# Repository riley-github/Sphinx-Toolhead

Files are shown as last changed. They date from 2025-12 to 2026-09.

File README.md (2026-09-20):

# Sphinx Toolhead

**File repository for the Sphinx toolhead**

Sphinx toolhead is aimed to be a high-performance toolhead with an emphasis on part cooling and rigidity.  
This project was built around the goal of printing a **quality 4-minute PLA Benchy**.  

Sphinx is a **work in progress!** If you have any suggested feel free to reach out of discord!

If you use this toolhead and modify or remix, please upload here or let me know on Instagram or Discord!  
📸 Instagram: [@practically_printed](https://instagram.com/practically_printed)  
💬 Sphinx Development Channel: [sphinx-dev](https://discord.gg/Rgn6Q9szn)

---

---

## 🧩 Notes

The current and most up to date version of Sphinx is called Sphinx tLW. This version utilizes a micro bowden approach in order to optimize for COM while not compromising on toolhead rigidity and so far has proved to work very well. 

- **Print Settings:** 8 walls, 8 top/bottom layers, 40% infill
- Print at least 4 of the Apex clips in either the Voron or Monolith folder

---

## 📸 Pictures (Sphinx tLW)

| | |
|:---:|:---:|
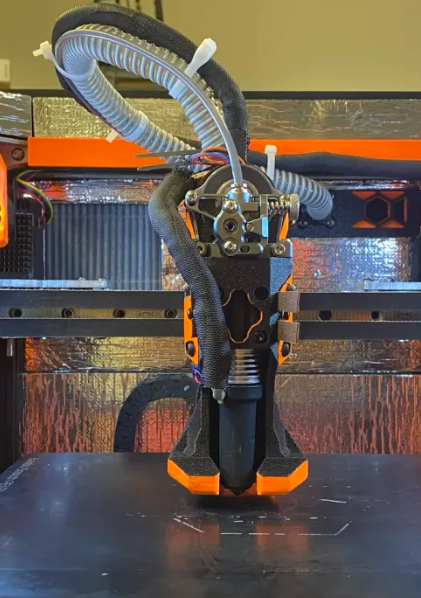
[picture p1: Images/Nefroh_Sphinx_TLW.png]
Nefroh Sphinx tLW
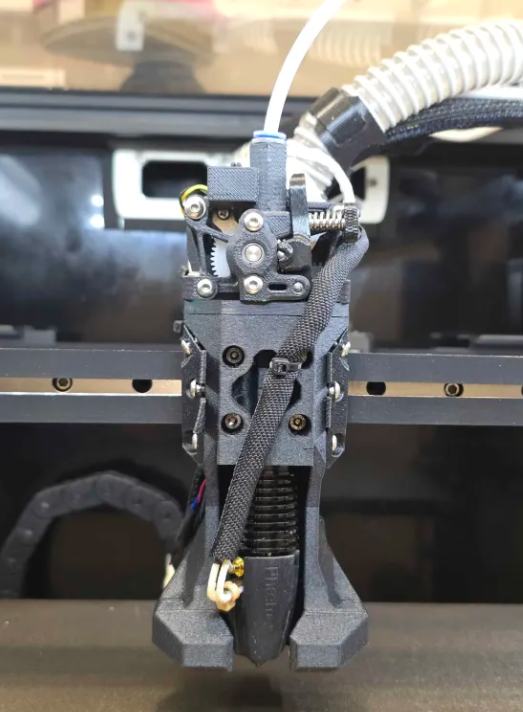
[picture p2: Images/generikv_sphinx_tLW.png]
generikv Sphinx tLW
|  |  |

Big thanks to discord users xyglotop and generikv for these images

---

## 📈 Input Shaper Results

| X IS Graph | Y IS Graph |
|:---:|:---:|
|  |  |

---

## ⚙️ Mass Specs / COM

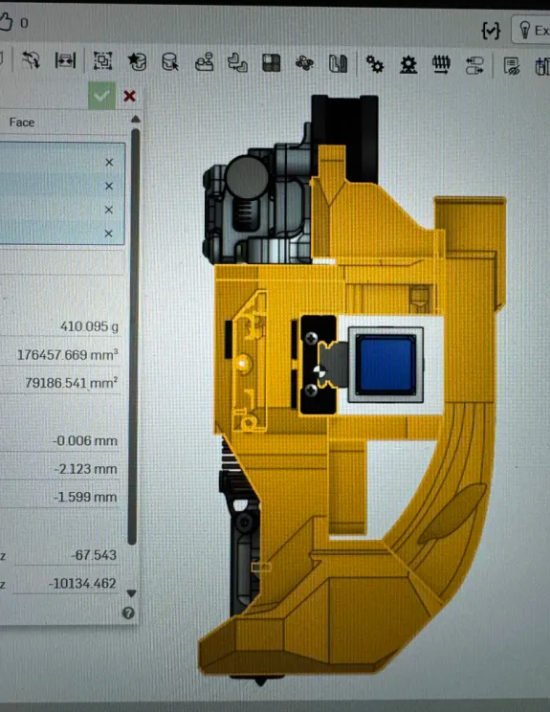
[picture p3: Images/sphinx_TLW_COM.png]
 

---

## 🧰 Currently Supported Hardware

**Hotends:**  
- Tricorn
- Goliath
- CHC XL
- Rapido UHF
- Dragon UHF

**Extruders:**  
- Sherpa Mini  

**Probes:**  
- Beacon
- Cartographer

---

## 🔧 Hardware in Progress

**Hotends:**    
- None unless requested    

**Extruders:**  
- Orbiter 2.0   

---

## 🌬️ Cooling Capability

The toolhead is built specifically around the duct geometry to maximize usable airflow for part cooling, with support for either WS9290 or WS7040 blowers. The 9290 blower is the optimal option is very aggressive and great for speed printing, but the 7040 duct will not disappoint. The goal of the ducts was to be able to print a perfect 5min benchy. 

## 5min 20sec ABS Benchy



---

## Other Information

Sphinx is meant to be used with an mgn12H rail carriage. A higher preload x rail is encouraged for best Input Shaper results 

COM for this toolhead was optimized using CNC Sherpa Mini and Tricorn, but will also be should be pretty similar with all other hotends

Tested successfully with **Siraya Tech ABS-CF**, though any filled abs or better is recommended.

---

## Acknowledgements

Huge shout out to everyone in the Excit3d and Monolith discord for helping me test and develop this toolhead! Couldn't have done it without their help

*© Sphinx Toolhead Project – Open-source and community-driven.*

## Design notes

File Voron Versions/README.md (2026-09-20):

# Voron Versions

Sphinx **tLW** builds for **Voron**-style carriages, packaged one zip per hotend.

Each archive is self-contained — download the one matching your hotend and print everything inside it. There is no need to mix files between archives.

---

## 📦 Available Builds

| Hotend | File |
|---|---|
| Dragon Ace MZE | `voron_sphinx_tLW_dragonAceMZE_sherpaMini.zip` |
| Dragon Ace Volcano | `voron_sphinx_tLW_DragonAceVolcano_sherpaMini.zip` |
| Goliath / CHC XL | `voron_sphinx_tLW_goliath_chcXL_sherpaMini.zip` |
| Rapido X / Rapido UHF | `voron_sphinx_tLW_rapidoXandUHF_sherpaMini.zip` |
| Tricorn | `voron_sphinx_tLW_tricorn_sherpa_mini.zip` |

All builds are for the **Sherpa Mini** extruder.

---

## 🧩 What's in Each Zip

Seven STEP files — six shared across every build, plus one hotend-specific main body:

| Part | Notes |
|---|---|
| `sphinx_main_body_<hotend>` | The only part that changes between archives |
| `left_clamp_voron` | Voron carriage mount |
| `right_clamp_voron` | Voron carriage mount |
| `extruder_mount` | Sherpa Mini |
| `sherpa_bracket` | Sherpa Mini |
| `mid_support` | |
| `rear_duct` | Part cooling |

The clamps are what make these Voron-specific. If you are on a Monolith carriage, use the [Monolith Versions](../Monolith%20Versions) folder instead — those ship `left_clamp_monolith` / `right_clamp_monolith` in place of these.

---

Generally Settings
- 8 walls
- 8 top / bottom layers
- 40% infill

For best COM results try to have slicer masses for each part close to what is listed below:
| Part | Slicer Mass Estimates |
|---|---|
| `sphinx_main_body_<hotend>` | 90g |
| `left_clamp_monolith` | 1-2g |
| `right_clamp_monolith` | 1-2g |
| `extruder_mount` | 20g |
| `sherpa_bracket` | 17g |
| `mid_support` | 6-7g |
| `rear_duct` | 34g |

Any filled ABS or better is recommended.  

---

See the [main README](../README.md) for supported hardware, cooling notes, and input shaper results.

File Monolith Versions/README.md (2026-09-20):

# Monolith Versions

Sphinx **tLW** builds for the **Monolith** carriage, packaged one zip per hotend.

Each archive is self-contained — download the one matching your hotend and print everything inside it. There is no need to mix files between archives.

---

## 📦 Available Builds

| Hotend | File |
|---|---|
| Dragon Ace MZE | `monolith_sphinx_tLW_dragonAceMZE.zip` |
| Dragon Ace Volcano | `monolith_sphinx_tLW_dragonAceVolcano_sherpaMini.zip` |
| Goliath / CHC XL | `monolith_sphinx_tLW_goliath_chcxl_sherpaMini.zip` |
| Rapido X / Rapido UHF | `monolith_sphinx_tLW_rapidoXandUHF_sherpaMini.zip` |
| Tricorn | `monolith_sphinx_tLW_tricorn_sherpaMini.zip` |

All builds are for the **Sherpa Mini** extruder.

---

## 🧩 What's in Each Zip

Seven STEP files — six shared across every build, plus one hotend-specific main body:

| Part | Notes |
|---|---|
| `sphinx_main_body_<hotend>` | The only part that changes between archives |
| `left_clamp_monolith` | Monolith carriage mount |
| `right_clamp_monolith` | Monolith carriage mount |
| `extruder_mount` | Sherpa Mini |
| `sherpa_bracket` | Sherpa Mini |
| `mid_support` | Common part |
| `rear_duct` | Common Part |

The clamps are what make these Monolith-specific. If you are on a Voron-style carriage, use the [Voron Versions](../Voron%20Versions) folder instead — those ship `left_clamp_voron` / `right_clamp_voron` in place of these.

---

## 🖨️ Print Settings

Generally Settings
- 8 walls
- 8 top / bottom layers
- 40% infill

For best COM results try to have slicer masses for each part close to what is listed below:
| Part | Slicer Mass Estimates |
|---|---|
| `sphinx_main_body_<hotend>` | 90g |
| `left_clamp_monolith` | 1-2g |
| `right_clamp_monolith` | 1-2g |
| `extruder_mount` | 20g |
| `sherpa_bracket` | 17g |
| `mid_support` | 6-7g |
| `rear_duct` | 34g |

Any filled ABS or better is recommended. Individuals have printed Sphinx out of anything from ABS-GF to PEEK

---

See the [main README](../README.md) for supported hardware, cooling notes, and input shaper results.

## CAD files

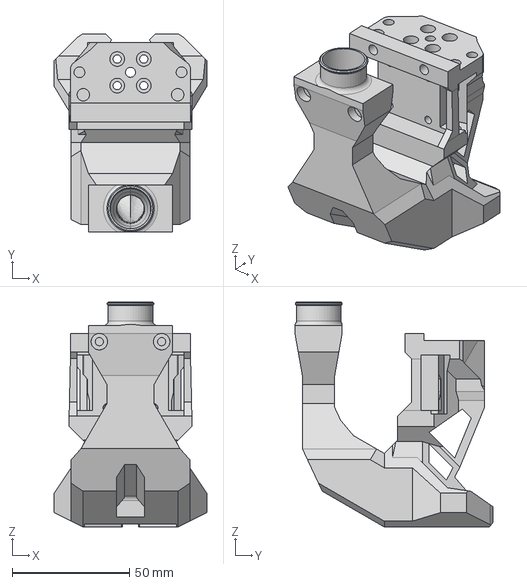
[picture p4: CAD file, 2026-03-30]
v3/goliath_chcXL_7040/v3_goliath_sherpa_7040_main_body.step
65.0 x 84.4 x 95.9 mm

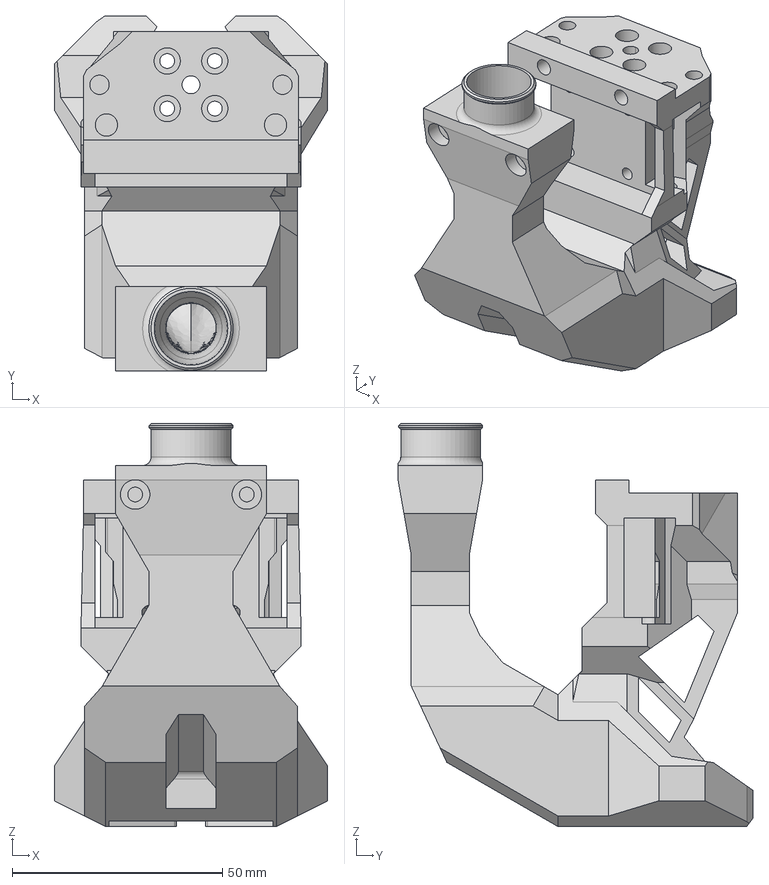
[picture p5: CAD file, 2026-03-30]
v3/goliath_chcxl_9290/v3_goliath_sherpa_9290_main_body.step
65.0 x 84.4 x 95.9 mm

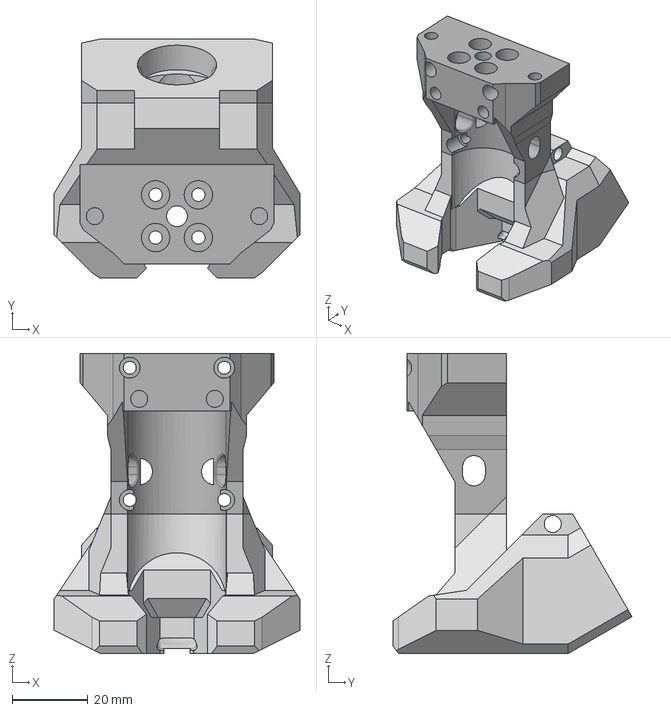
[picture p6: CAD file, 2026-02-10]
Sphinx_Single_Inlet_Parts/Assembly 2.step
65.0 x 63.2 x 79.4 mm

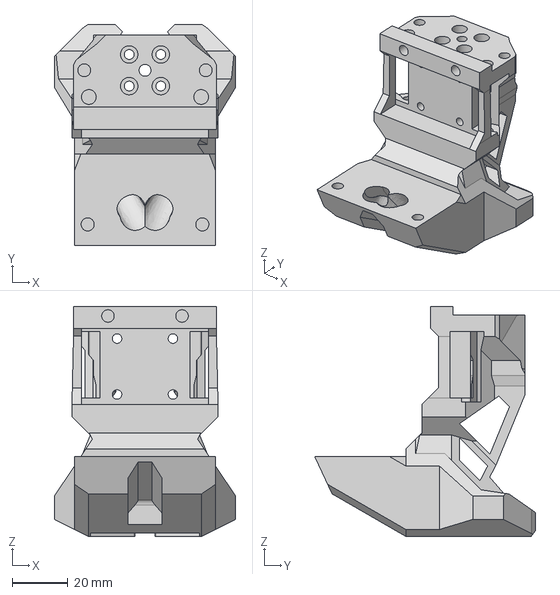
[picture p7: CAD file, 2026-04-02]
v3/tricorn_7040/v3_tricorn_sherpa_7040_main_body_parted.step
65.0 x 79.0 x 82.4 mm

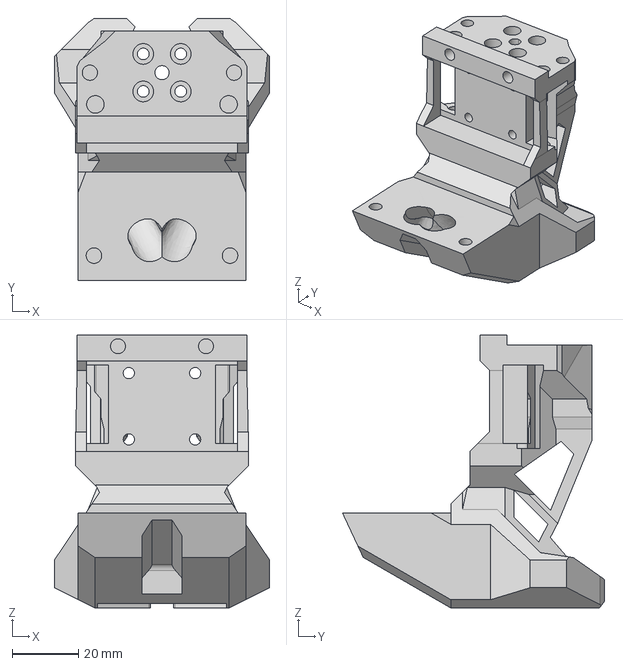
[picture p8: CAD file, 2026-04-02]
v3/tricorn_9290/v3_tricorn_sherpa_main_body_parted.step
65.0 x 79.0 x 82.4 mm

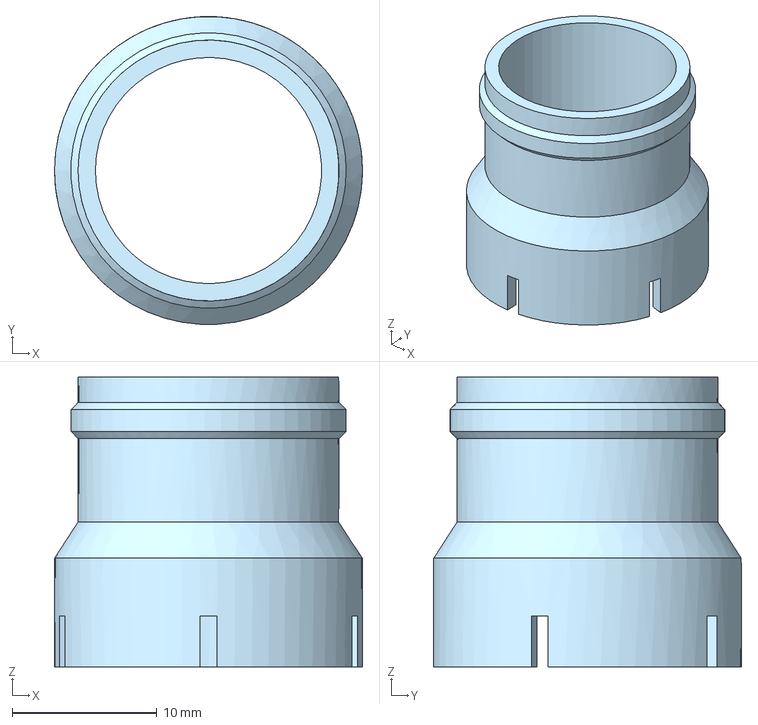
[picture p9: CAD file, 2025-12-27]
CPAP Clamp (2).step
21.2 x 21.2 x 20.0 mm

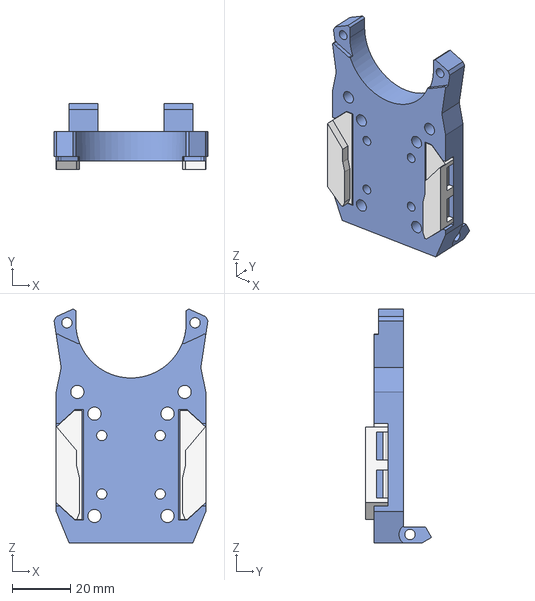
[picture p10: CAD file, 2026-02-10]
Sphinx_Single_Inlet_Parts/printed_toolhead_bracket_sherpa (1).step
52.6 x 22.6 x 80.1 mm

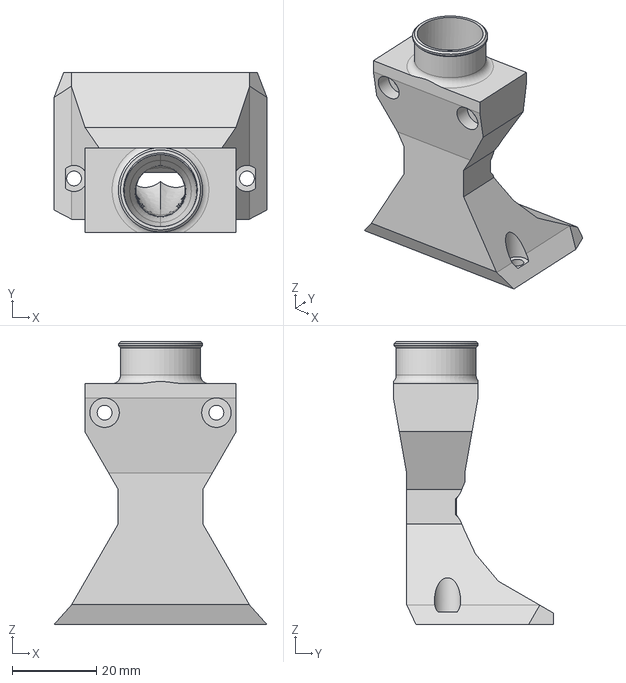
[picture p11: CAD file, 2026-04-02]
v3/tricorn_7040/v3_tricorn_sherpa_7040 - v3_rear_duct.step
50.5 x 38.0 x 67.2 mm

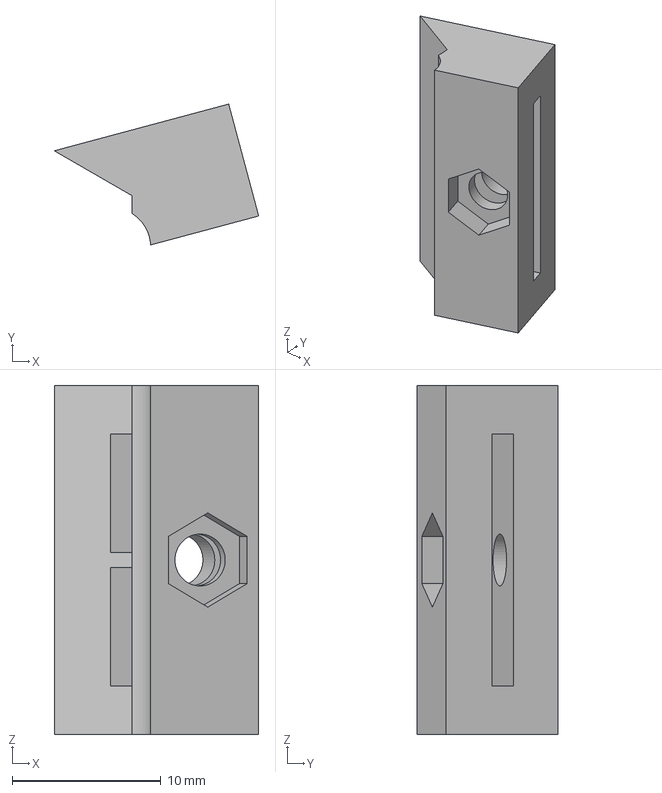
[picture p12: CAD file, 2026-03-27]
v3/beta/v3_chcxl_sherpa_micro - mgn9_belt_clamp_left.step
13.8 x 9.48 x 23.5 mm

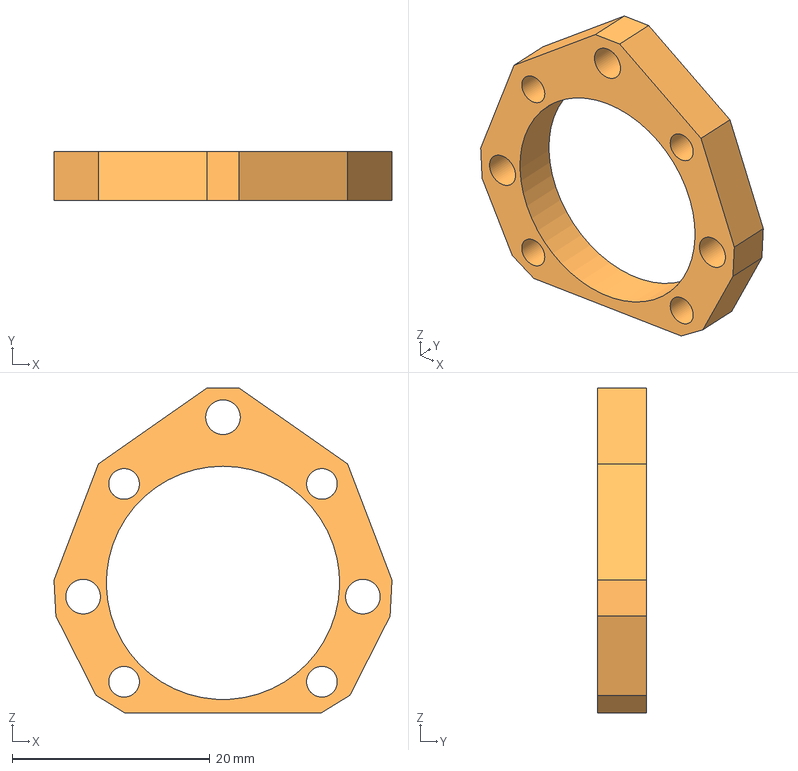
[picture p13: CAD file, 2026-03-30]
v3/goliath_chcxl_9290/2510_fan_mount_goliath_chcxl.step
34.2 x 5.00 x 32.8 mm

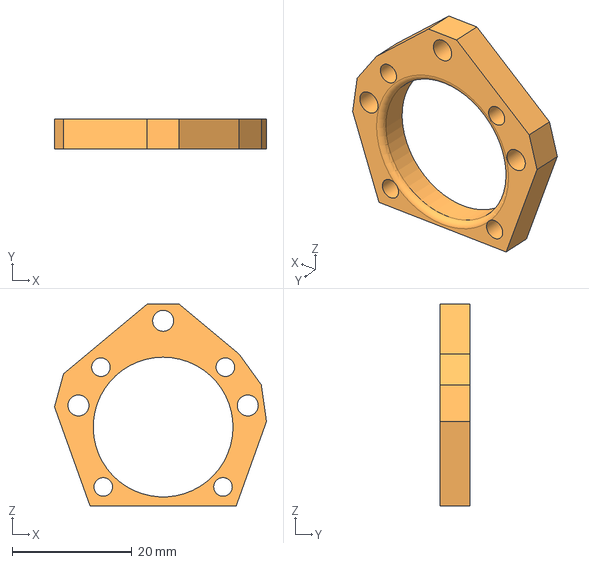
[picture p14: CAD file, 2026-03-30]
v3/rapido_uhf_sherpa_9290/2510_rapido_hotend_fan_mount.step
35.4 x 5.00 x 33.7 mm

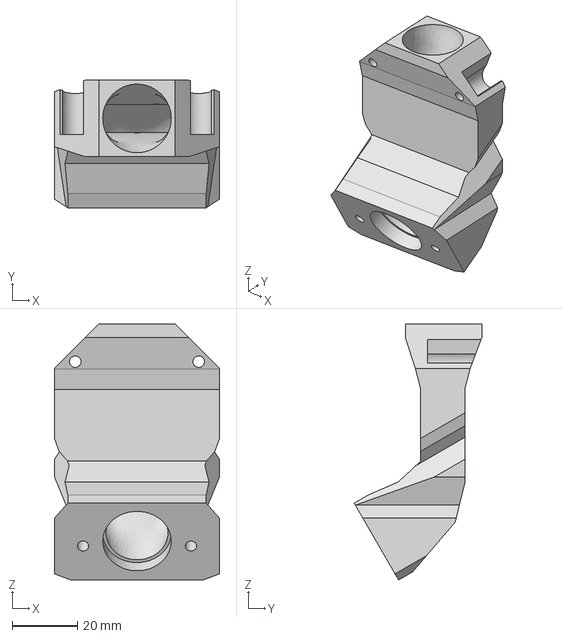
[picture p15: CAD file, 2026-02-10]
RapidoUHF_Sherpa_Single/rear_duct - duct (1).step
50.5 x 39.1 x 78.4 mm

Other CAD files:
v3/rapido_uhf_sherpa_9290/v3_rapido2uhf_sherpa_9290_main_body.step
RapidoUHF_Sherpa_Single/single_rapidoUHF_sherpa - rUHF_sherpa.step
Tricorn_Sherpa_Single_Inlet/Sphinx_single_tricorn_sherpa.step
v3/beta/v3_chcxl_sherpa_micro - sphinx_chcxl_sherpaMicron_P4A (1).step
v3/tricorn_9290/v3_tricorn_sherpa - v3_rear_duct.step
RapidoUHF_Sherpa_Single/printed_toolhead_bracket_sherpa (2).step
RapidoUHF_Sherpa_Single/rear_duct - top_support_sherpa (1).step
Sphinx_Single_Inlet_Parts/rear_duct - duct.step
Sphinx_Single_Inlet_Parts/rear_duct - top_support_orb.step
Sphinx_Single_Inlet_Parts/rear_duct - top_support_sherpa.step
Sphinx_Single_Inlet_Parts/sherpa_tricorn_dual_cpap.step
Sphinx_Single_Inlet_Parts/sphinx_2_4_26.step
Sphinx_Single_Inlet_Parts/sphinx_single_tricorn_orb.step
v3/beta/v3_chcxl_sherpa_micro - 2510_fan_mount.step
v3/beta/v3_chcxl_sherpa_micro - duct_support_generic.step
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

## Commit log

2025-10-17 Update hotends list in README
2025-10-17 Update README with printing instructions
    Added printing instructions for toolhead supports.
2025-10-20 Add Sphinx Toolhead image to README
    Added an image of the Sphinx Toolhead to the README.
2025-10-20 Modify image tags for Sphinx Toolhead
    Updated image tags in README for better display.
2025-10-22 Add note about graph creation in README
    Added a note about the graphs being made with the printed toolhead bracket.
2025-10-22 Update README with note on graph creation
    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
2026-01-13 Add files via upload
    1/12/26
    Updated for monolith 9mm belts
    [printed_toolhead_bracket.step]
2026-03-30 Add sphinx v3 information for CPAP fan
2026-03-30 Add sphinx v3 description for rapido2 devices
2026-03-30 Update README with toolhead features and specifications
    Added additional details about toolhead compatibility, cooling capabilities, and mounting options.
2026-09-03 Remove outdated, non-functional toolhead configurator
    [assembly_v2.stl, body_chc-xl_sherpa-micro_v3.stl, body_dragon-uhf_sherpa_monolith.stl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]
2026-09-03 Add beta Voron Sphinx tLW Goliath/chcXL/SherpaMini parts
    [voron_sphinx_tLW_-_extruder_mount_sherpaMini.step, voron_sphinx_tLW_-_left_clamp_voron.step, voron_sphinx_tLW_-_mid_support.step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]
2026-09-20 Remove beta Voron Sphinx tLW Goliath/chcXL/SherpaMini folder
    [voron_sphinx_tLW_-_extruder_mount_sherpaMini.step, voron_sphinx_tLW_-_left_clamp_voron.step, voron_sphinx_tLW_-_mid_support.step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]
2026-09-20 Remove Monolith and Voron folders
    [Apex clip 9mm.step, Apex clip sphinx_voron.step, sphinx_tLW_ middle_braket.step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]
2026-09-20 Clarify part descriptions and add slicer mass estimates
    Updated descriptions for mid_support and rear_duct to clarify their common usage. Added slicer mass estimates for various parts to improve printing guidance.
2026-09-20 Update README with print settings and mass estimates
    Added general print settings and slicer mass estimates for Voron parts.
2026-09-20 Remove configurator tooling and CAD source tree
    Drops the leftover conversion scripts that fed the removed configurator
    (batch_convert_to_glb.py, batch_convert_to_stl.py, convert_voron_monolith.py)
    along with cpap_clamp.bin, plus the CAD/ STEP library they read from.
    [assembly_orbiter_tricorn_v2.step, assembly_v2.step, body_chc-xl_sherpa-micro_v3.step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]
2026-10-16 Add cnSphinx CNC plate variant with monolith and voron files
2026-10-16 Add cnSphinx CNC plate variant with CAD and COM images
2026-10-16 Update README with cpap ducts information
    Add note about FDM printed cpap ducts availability.
2026-10-16 Revise README for cnSphinx toolhead updates
    Updated README to reflect upcoming long hotend compatibility and clarified SLM printing material.
2026-10-16 Add shared cnSphinx plates and ducts, document M3x30 standoffs
2026-10-19 Add FDM center housing option for voron cnSphinx
    Labels both carriage tables' center rows by process so the SLM and FDM
    options are distinguishable.
2026-10-19 Add FDM center housing option for monolith cnSphinx
    Both carriages now offer SLM and FDM center housings.
2026-10-20 Add Sphinx tLW assembly STEP files
    Full monolith and voron tLW assemblies, 7 parts each.
2026-10-20 Add hardware BOM for common parts and hotend kits
    Claude-Session: https://claude.ai/code/session_0174dh7iXUv22wq4UNgTZ3WX
2026-10-20 Move BOM.md into Sphinx tLW Assemblies and BOM
    Updates the main README link to the new path and fixes the BOM's
    back-link to point up a level.
2026-10-20 Replace cnSphinx CPAP ducts with revised exports
    Swaps Tricorn_Short_duct.step and chube_compact_duct.step for the new
    tricornShort_duct.step and chubeCompact_duct.step, and updates the
    common parts table to match.
2026-10-26 Add cnSphinx prototype build photos to README
    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
2026-10-26 Move cnSphinx prototype photos above Design section
    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
